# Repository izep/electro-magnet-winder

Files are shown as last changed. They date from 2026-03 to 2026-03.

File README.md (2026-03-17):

# Electro-Magnet Winder

A DIY machine for winding precision electro-magnets and coils, powered by an RP2040-Zero microcontroller.

## Project Structure

| Path | Contents |
|---|---|
| `src/winder.ino` | Firmware (single unified sketch) |
| `wiring/` | Wiring diagrams and pinout references |
| `model/` | 3D-printable STL files for the enclosure |

## Hardware Components

- **Microcontroller**: RP2040-Zero (Waveshare/clone)
- **Motor 1 (winding)**: 28BYJ-48 + ULN2003 driver board
- **Motor 2 (traverse/guide)**: 28BYJ-48 + ULN2003 driver board
- **Display**: SH5461AS 4-digit 7-segment (common cathode)
- **Input**: KY-040 rotary encoder

See `wiring/rp2040-zero-dual-stepper.md` for the full pinout and wiring diagram.

## Getting Started

1. Follow the wiring diagram in `wiring/rp2040-zero-dual-stepper.md`.
2. Install the **Earle Philhower RP2040 Arduino core** in the Arduino IDE.
3. Open `src/winder.ino` and upload to the RP2040-Zero.

## Using the Firmware

On power-up the machine runs a brief motor test (display shows `----`) to confirm both motors are wired correctly. Both motors step forward 4 steps then back 4 steps before the menu appears.

### Menu flow

The **encoder button** advances through each setting. Rotate the encoder to change the current value.

| Display | State | Encoder action |
|---|---|---|
| `0001`  | Layers | Rotate to set number of winding layers (±1, range 1–99) |
| `L 20`  | Spool length | Rotate to set magnet/coil length in mm (±1 mm, range 1–999) |
| `A 28`  | Wire gauge | Rotate to cycle AWG presets: 22, 26, 28, 30, 32, 36, 40 |
| `Hone`  | **Align Guide** | **Rotate to jog guide motor manually; align wire to spool start.** |
| `go` | Ready | Press button to start winding |
| `0000`  | **Winding** | Display counts turns — press button to stop (returns to `Hone`) |

Total turns are computed automatically when you press start:

```
turns_per_layer = floor(spool_length_mm / wire_diameter_mm)
total_turns     = layers × turns_per_layer
```

For example: 3 layers, 20 mm spool, 28 AWG (0.321 mm) → 62 turns/layer → **186 total turns**.

When winding completes (target reached) or is stopped, the machine returns to the turn count setting screen.

### Guide motor calibration

2 revolutions of Motor 2 = 3.5 mm of linear travel. This is fixed in firmware as `GUIDE_STEPS_PER_MM = (2 × 2048) / 3.5 ≈ 1170`. Adjust this constant in `winder.ino` if your lead screw or drive mechanism differs.

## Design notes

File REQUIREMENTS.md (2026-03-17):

# Electro-Magnet Winder - Requirements

## Overview
A DIY machine for winding precision electro-magnets and coils, powered by an RP2040-Zero microcontroller.

## Hardware Specifications
- **Controller**: Waveshare RP2040-Zero
- **Actuators**: 
  - 2x 28BYJ-48 Stepper Motors (64:1 gear ratio)
  - 2x ULN2003 Driver Boards
- **Input**: 
  - KY-040 Rotary Encoder (Navigation and count adjustment)
- **Output**: 
  - 4-Digit 7-Segment Display (SH5461AS, common cathode) for turn count/status.

## Functional Requirements

1. **Menu-driven configuration**: Set target turns, spool/magnet length, and wire gauge before winding.
2. **Automatic Winding**: Press start; machine winds to target turn count and stops automatically.
3. **Dual Motor Sync**:
   - Motor 1: Winding (rotation)
   - Motor 2: Wire guide (linear traverse, ping-pong across spool length)
4. **Display**: Real-time turn count while winding; settings shown in menu.
5. **Wire gauge presets**: 22, 26, 28, 30, 32, 36, 40 AWG — selectable at runtime.
6. **Startup test**: Brief motor movement on power-up to verify coil wiring.
7. **Memory**: Persistence of settings (deferred to future version).

## Technical Stack
- **Firmware**: C++/Arduino (Earle Philhower RP2040 core)
- **CAD**: STL models for 3D printed enclosure
- **Documentation**: Markdown-based wiring and assembly guides

## Roadmap

- [x] Initial wiring and pinout defined
- [x] Basic motor/display test sketch
- [x] Implement traverse/winding sync logic (ping-pong guide)
- [x] Menu system: target turns, spool length, wire gauge, start/stop
- [x] Wire gauge presets (22–40 AWG, selectable at runtime)
- [x] Startup motor test sequence
- [x] Persistence of settings (EEPROM)
- [x] Handle motor release and emergency stop
- [ ] 3D print and assemble enclosure

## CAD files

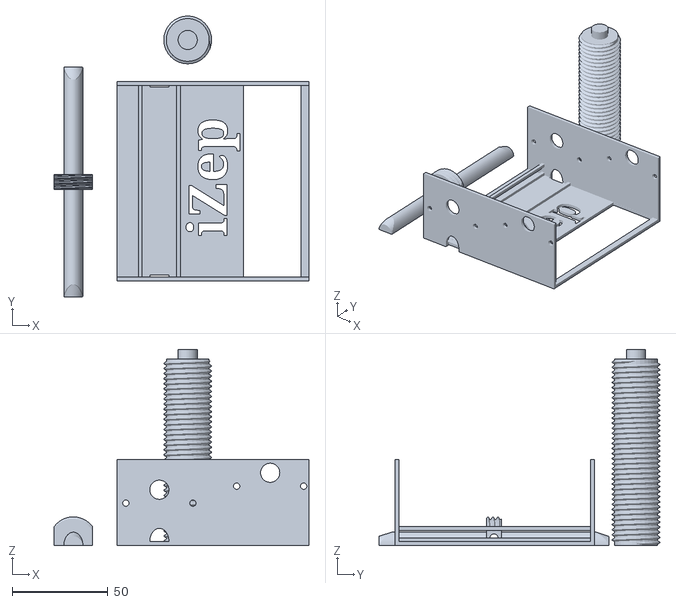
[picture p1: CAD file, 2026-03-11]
model/winder_box.stl
132.9 x 146.7 x 102.4

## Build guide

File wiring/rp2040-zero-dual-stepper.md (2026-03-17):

# RP2040-Zero — Dual Stepper + Display + Rotary Encoder

## Components

| Component | Purpose |
|---|---|
| RP2040-Zero | Main controller |
| 2× 28BYJ-48 + ULN2003 driver boards | Stepper motors |
| SH5461AS 4-digit 7-segment display | Status / count display |
| KY-040 rotary encoder | Adjustment knob + push-button |

The RP2040-Zero exposes **20 GPIO via pin headers**: GP0–GP15 and GP26–GP29.
GP16 drives the onboard WS2812B NeoPixel; GP17–GP25 are castellated-edge only.

To fit within 20 pins, GP0 and GP1 serve dual roles:
- **Menu phase** — reconfigured as `INPUT_PULLDOWN` for encoder CLK/DT
- **Winding phase** — reconfigured as `OUTPUT` for Motor 1 IN1/IN2

GP29 (encoder SW / emergency stop) is always `INPUT_PULLUP` regardless of phase.
The decimal-point segment (DP) is omitted; segments A–G are sufficient for all display needs.

---

## Wiring Diagram

```mermaid
graph LR
    subgraph PWR["⚡ Power"]
        P5V((5 V))
        P3V((3.3 V))
        PGND((GND))
    end

    subgraph RP["RP2040-Zero"]
        R0["GP0  Motor 1 IN1 / Enc CLK ✱"]
        R1["GP1  Motor 1 IN2 / Enc DT  ✱"]
        R2["GP2  Motor 1 IN3"]
        R3["GP3  Motor 1 IN4"]
        R4["GP4  Motor 2 IN1"]
        R5["GP5  Motor 2 IN2"]
        R6["GP6  Motor 2 IN3"]
        R7["GP7  Motor 2 IN4"]
        R8["GP8  Seg A"]
        R9["GP9  Seg B"]
        R10["GP10 Seg C"]
        R11["GP11 Seg D"]
        R12["GP12 Seg E"]
        R13["GP13 Seg F"]
        R14["GP14 Seg G"]
        R15["GP15 Digit 0"]
        R26["GP26 Digit 1"]
        R27["GP27 Digit 2"]
        R28["GP28 Digit 3"]
        R29["GP29 Enc SW (always)"]
        RGND["GND"]
    end

    subgraph U1["ULN2003 Driver #1"]
        U1IN["IN1-IN4"]
        U1VCC["VCC / +"]
        U1GND["GND / -"]
        U1OUT["Motor JST"]
    end

    subgraph U2["ULN2003 Driver #2"]
        U2IN["IN1-IN4"]
        U2VCC["VCC / +"]
        U2GND["GND / -"]
        U2OUT["Motor JST"]
    end

    subgraph DISP["SH5461AS (common cathode)"]
        DSA["Seg A–G"]
        DDG["Digit 0–3 cathodes"]
    end

    subgraph KY["KY-040 Rotary Encoder"]
        KCLK["CLK (A)"]
        KDT["DT (B)"]
        KSW["SW"]
        KVCC["VCC"]
        KGND["GND"]
    end

    M1["Motor 1\n28BYJ-48"]
    M2["Motor 2\n28BYJ-48"]

    %% Motor 1 wiring
    R0 & R1 & R2 & R3 -- "IN1-IN4" --> U1IN
    %% Motor 2 wiring
    R4 & R5 & R6 & R7 -- "IN1-IN4" --> U2IN

    %% Display segments (via 150Ω resistors)
    R8 & R9 & R10 & R11 & R12 & R13 & R14 -- "150Ω" --> DSA
    %% Display digit selects
    R15 & R26 & R27 & R28 --> DDG

    %% Encoder (CLK/DT shared with Motor 1 IN1/IN2 — menu phase only)
    R0 -.->|"menu only ✱"| KCLK
    R1 -.->|"menu only ✱"| KDT
    R29 --> KSW

    %% Motors
    U1OUT --> M1
    U2OUT --> M2

    %% Power 5V
    P5V --> U1VCC
    P5V --> U2VCC

    %% Power 3.3V
    P3V --> KVCC

    %% GND
    PGND --> U1GND
    PGND --> U2GND
    PGND --> KGND
    PGND --> RGND
```

---

## RP2040-Zero Pin Reference

> ✱ GP0 and GP1 are shared. The firmware reconfigures them at each phase boundary.

| GPIO | Role | Connected to | Phase |
|---|---|---|---|
| GP0 | Motor 1 IN1 | ULN2003 #1 IN1 | Winding |
| GP0 ✱ | Encoder CLK | KY-040 CLK | Menu |
| GP1 | Motor 1 IN2 | ULN2003 #1 IN2 | Winding |
| GP1 ✱ | Encoder DT | KY-040 DT | Menu |
| GP2 | Motor 1 IN3 | ULN2003 #1 IN3 | Both |
| GP3 | Motor 1 IN4 | ULN2003 #1 IN4 | Both |
| GP4 | Motor 2 IN1 | ULN2003 #2 IN1 | Both |
| GP5 | Motor 2 IN2 | ULN2003 #2 IN2 | Both |
| GP6 | Motor 2 IN3 | ULN2003 #2 IN3 | Both |
| GP7 | Motor 2 IN4 | ULN2003 #2 IN4 | Both |
| GP8 | Segment A | SH5461AS pin 11 (via 150 Ω) | Both |
| GP9 | Digit 1 cathode | SH5461AS pin 12 (leftmost) | Both |
| GP10 | Segment C | SH5461AS pin 4 (via 150 Ω) | Both |
| GP11 | Segment D | SH5461AS pin 2 (via 150 Ω) | Both |
| GP12 | Segment E | SH5461AS pin 1 (via 150 Ω) | Both |
| GP13 | Digit 2 cathode | SH5461AS pin 9 | Both |
| GP14 | Segment G | SH5461AS pin 5 (via 150 Ω) | Both |
| GP15 | Segment F | SH5461AS pin 10 (via 150 Ω) | Both |
| GP26 | Digit 3 cathode | SH5461AS pin 8 | Both |
| GP27 | Segment B | SH5461AS pin 7 (via 150 Ω) | Both |
| GP28 | Digit 4 cathode | SH5461AS pin 6 (rightmost) | Both |
| GP29 | Encoder SW | KY-040 SW (emergency stop) | Both |

DP segment is not connected. All 20 header-accessible GPIO are used.

---

## RP2040-Zero → ULN2003 Stepper Detail

The RP2040-Zero's 3.3 V GPIO outputs exceed the ULN2003's ~2.5 V input
threshold — no level shifter required. Motor coil power stays on the 5 V rail
via the ULN2003 boards.

### Motor 1 (GP0–GP3)

| RP2040-Zero | ULN2003 #1 |
|---|---|
| GP0 | IN1 |
| GP1 | IN2 |
| GP2 | IN3 |
| GP3 | IN4 |

### Motor 2 (GP4–GP7)

| RP2040-Zero | ULN2003 #2 |
|---|---|
| GP4 | IN1 |
| GP5 | IN2 |
| GP6 | IN3 |
| GP7 | IN4 |

---

## RP2040-Zero → SH5461AS Display Detail

The SH5461AS is a **common-cathode** display. To light a segment: pull the
digit pin LOW and the segment pin HIGH. Cycle through digits rapidly to
multiplex.

Place a **150 Ω resistor** in series with each segment line (GP8–GP14). At
3.3 V with a ~2 V LED forward voltage and 25% multiplex duty cycle this gives
roughly 8–9 mA per segment — adequate brightness without overloading the GPIO.

### Physical Pinout

The SH5461AS has **12 pins** — 6 on the bottom edge and 6 on the top edge.

**Finding pin 1:** Hold the display face-toward-you with the decimal points
along the bottom edge. The small circular indent (or dot) moulded into the
plastic body marks the **pin 1 end**. Pin 1 is the bottom-left pin.

```
        FRONT VIEW  (decimal points along bottom, pin-1 dot at bottom-left)

        pin 12  11  10   9   8   7
              │   │   │   │   │   │
         ┌────┴───┴───┴───┴───┴───┴────┐
         │                             │
         │   ┌──┐  ┌──┐  ┌──┐  ┌──┐   │
         │   │  │  │  │  │  │  │  │   │
         │   └──┘  └──┘  └──┘  └──┘   │
         │    D1    D2    D3    D4     │
         │    .     .     .     .     │  ← decimal points (not wired)
         └────┬───┬───┬───┬───┬───┬───┘
              │   │   │   │   │   │
         ● pin 1   2   3   4   5   6
         (dot)
```

Pin functions:

| Pin | Function | Pin | Function |
|-----|---|-----|---|
|  1  | Segment E |  7  | Digit 3 cathode (D3) |
|  2  | Segment D |  8  | Digit 2 cathode (D2) |
|  3  | Segment DP |  9  | Segment F |
|  4  | Segment C | 10  | Digit 1 cathode (D1, leftmost) |
|  5  | Segment G | 11  | Segment A |
|  6  | Digit 4 cathode (D4, rightmost) | 12 | Segment B |

### Wiring to RP2040-Zero

| RP2040-Zero | Resistor | SH5461AS pin | Signal |
|---|---|---|---|
| GP8  | 150 Ω | Pin 11 | Segment A |
| GP27 | 150 Ω | Pin 7  | Segment B |
| GP10 | 150 Ω | Pin 4  | Segment C |
| GP11 | 150 Ω | Pin 2  | Segment D |
| GP12 | 150 Ω | Pin 1  | Segment E |
| GP15 | 150 Ω | Pin 10 | Segment F |
| GP14 | 150 Ω | Pin 5  | Segment G |
| GP9  | — | Pin 12 | Digit 1 cathode (leftmost) |
| GP13 | — | Pin 9  | Digit 2 cathode |
| GP26 | — | Pin 8  | Digit 3 cathode |
| GP28 | — | Pin 6  | Digit 4 cathode (rightmost) |

Pin 3 (Segment DP) is left unconnected.

---

## GP0 / GP1 Pin Sharing

GP0 and GP1 connect to **both** ULN2003 #1 (IN1/IN2) and the KY-040 encoder (CLK/DT).
The firmware switches their role at phase boundaries:

| Phase | pinMode | Effect |
|---|---|---|
| Menu | `INPUT_PULLDOWN` | KY-040's 10 kΩ pull-ups drive the lines; ULN2003 inputs held LOW (motors off) |
| Winding | `OUTPUT` | Normal motor step outputs; encoder CLK/DT signals are ignored |

`enterMenuMode()` detaches the CLK interrupt, reconfigures to `INPUT_PULLDOWN`, then re-attaches.  
`enterWindingMode()` detaches the interrupt and reconfigures to `OUTPUT LOW`.

GP29 (encoder SW) is wired **only** to the KY-040 SW pin and stays `INPUT_PULLUP` always,
so the emergency-stop button works during both menu navigation and active winding.

---

## Power Summary

| Rail | Feeds |
|---|---|
| 5 V (USB or external ≥ 1 A) | ULN2003 boards |
| 3.3 V (RP2040-Zero onboard reg) | KY-040, SH5461AS segments |
| GND | Shared — connect all grounds together |

Both motors can draw ~240 mA each under load (480 mA combined). Use a
dedicated external 5 V supply for the ULN2003 boards when both motors run.

---

## Stepper Half-Step Sequence

| Step | IN4 | IN3 | IN2 | IN1 | Nibble |
|---|-----|-----|-----|-----|---|
| 1 | 0 | 0 | 0 | 1 | 0x1 |
| 2 | 0 | 0 | 1 | 1 | 0x3 |
| 3 | 0 | 0 | 1 | 0 | 0x2 |
| 4 | 0 | 1 | 1 | 0 | 0x6 |
| 5 | 0 | 1 | 0 | 0 | 0x4 |
| 6 | 1 | 1 | 0 | 0 | 0xC |
| 7 | 1 | 0 | 0 | 0 | 0x8 |
| 8 | 1 | 0 | 0 | 1 | 0x9 |

Reverse the table for reverse direction.
**2048 steps = 1 full revolution** (64:1 gearbox × 32 full steps, half-step mode).

---

## Firmware

The full Arduino sketch lives in [`../src/winder.ino`](../src/winder.ino).
Use the **Earle Philhower RP2040 Arduino core** (`arduino-pico`). No extra
libraries needed — all I/O is direct GPIO.

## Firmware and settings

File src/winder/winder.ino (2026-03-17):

#include "hardware/gpio.h"
/**
 * Electro-Magnet Winder Firmware
 * Target: Waveshare RP2040-Zero
 * Core:   Earle Philhower RP2040 Arduino core
 */

#include <Arduino.h>
#include <EEPROM.h>
#include "EEPROM_Settings.h"

SettingsManager settingsManager;

// ── Pin assignments ──────────────────────────────────────────────────────────

const int M1[4]  = {0, 1, 2, 3};             // Winding motor  (ULN2003 #1)
const int M2[4]  = {4, 5, 6, 7};             // Traverse motor (ULN2003 #2)
const int SEG[7] = {8, 27, 10, 11, 12, 15, 14};  // Segments A, B, C, D, E, F, G
const int DIG[4] = {9, 13, 26, 28};             // Digit cathodes 1, 2, 3, 4

#define ENC_CLK  0
#define ENC_DT   1
#define ENC_SW  29

// ── Motor constants ──────────────────────────────────────────────────────────

const int   STEPS_PER_REV      = 4096;       // 28BYJ-48 half-step (64:1 gear)
const float GUIDE_STEPS_PER_MM = 1575.385f;  // From calibration (61440 steps / 39mm)
const int   STEP_DELAY_MS      = 2;          // ms between winding motor steps

// ── AWG wire diameter presets ────────────────────────────────────────────────

struct WireGauge { uint8_t awg; float diameter_mm; };

const WireGauge GAUGES[] = {
  {22, 0.644f}, {26, 0.405f}, {28, 0.321f}, {30, 0.255f},
  {32, 0.202f}, {36, 0.127f}, {40, 0.079f},
};
const int NUM_GAUGES = (int)(sizeof(GAUGES) / sizeof(GAUGES[0]));

// ── Half-step sequence ───────────────────────────────────────────────────────

const uint8_t HALF_STEP[8] = {0x1, 0x3, 0x2, 0x6, 0x4, 0xC, 0x8, 0x9};

// ── 7-segment patterns ───────────────────────────────────────────────────────

const uint8_t DIGIT_PAT[10] = {
  0b00111111, 0b00000110, 0b01011011, 0b01001111, 0b01100110,
  0b01101101, 0b01111101, 0b00000111, 0b01111111, 0b01101111,
};

const uint8_t SEG_BLANK = 0x00;
const uint8_t SEG_DASH  = 0x40;
const uint8_t SEG_L     = 0x38;
const uint8_t SEG_A_UP  = 0x77;
const uint8_t SEG_G_LO  = 0x6F;
const uint8_t SEG_O_LO  = 0x5C;
const uint8_t SEG_D_LO  = 0x5E;
const uint8_t SEG_N_LO  = 0x54;
const uint8_t SEG_E_LO  = 0x79;
const uint8_t SEG_H     = 0x76;
const uint8_t SEG_C_UP  = 0x39;

// ── State & Defaults ─────────────────────────────────────────────────────────

enum State { MENU_LAYERS, MENU_LENGTH, MENU_GAUGE, MENU_DIR, MENU_HOME, MENU_START, WINDING };
State state = MENU_LAYERS;

int targetLayers  = 10;   // Default: 10 layers
int spoolLengthMM = 50;   // Default: 50 mm
int gaugeIndex    = 0;    // Default: 22 AWG
int guideDir      = -1;   // Default: CC (-1)

uint8_t displayBuf[4] = {SEG_BLANK, SEG_BLANK, SEG_BLANK, SEG_BLANK};

// ── Winding state ────────────────────────────────────────────────────────────

int           computedTurns = 0;
long          totalStepsM1 = 0;
long          totalStepsM2 = 0;
int           currentTurns = 0;
int           stepIdx1     = 0;
int           stepIdx2     = 0;
unsigned long lastStepTime = 0;

volatile int encoderDelta = 0;

void onEncoderCLK() {
  static uint32_t lastISR = 0;
  uint32_t now = millis();
  if (now - lastISR < 1) return;
  lastISR = now;
  encoderDelta += (digitalRead(ENC_DT) == HIGH) ? -1 : 1;
}

// ── Motor helpers ────────────────────────────────────────────────────────────

void writeMotor(const int pins[4], uint8_t nibble) {
  for (int i = 0; i < 4; i++) digitalWrite(pins[i], (nibble >> i) & 1);
}

void stepMotor1(int dir) {
  stepIdx1 = (stepIdx1 + dir + 8) % 8;
  writeMotor(M1, HALF_STEP[stepIdx1]);
  totalStepsM1 += dir;
}

void stepMotor2(int dir) {
  stepIdx2 = (stepIdx2 + dir + 8) % 8;
  writeMotor(M2, HALF_STEP[stepIdx2]);
  totalStepsM2 += dir;
}

void releaseMotors() { writeMotor(M1, 0); writeMotor(M2, 0); }

void enterMenuMode() {
  writeMotor(M1, 0);
  detachInterrupt(digitalPinToInterrupt(ENC_CLK));
  pinMode(ENC_CLK, INPUT_PULLDOWN);
  pinMode(ENC_DT,  INPUT_PULLDOWN);
  encoderDelta = 0;
  attachInterrupt(digitalPinToInterrupt(ENC_CLK), onEncoderCLK, FALLING);
}

void enterWindingMode() {
  detachInterrupt(digitalPinToInterrupt(ENC_CLK));
  pinMode(ENC_CLK, OUTPUT); digitalWrite(ENC_CLK, LOW);
  pinMode(ENC_DT,  OUTPUT); digitalWrite(ENC_DT,  LOW);
}

// ── Display helpers ──────────────────────────────────────────────────────────

void refreshDisplay() {
  static uint8_t digit = 0;
  for (int i = 0; i < 4; i++) digitalWrite(DIG[i], HIGH);
  uint8_t pat = displayBuf[digit];
  for (int i = 0; i < 7; i++) digitalWrite(SEG[i], (pat >> i) & 1);
  digitalWrite(DIG[digit], LOW);
  digit = (digit + 1) % 4;
}

void showNumber(int n) {
  n = constrain(n, 0, 9999);
  displayBuf[0] = (n >= 1000) ? DIGIT_PAT[n / 1000] : SEG_BLANK;
  displayBuf[1] = (n >= 100)  ? DIGIT_PAT[(n / 100) % 10] : SEG_BLANK;
  displayBuf[2] = (n >= 10)   ? DIGIT_PAT[(n / 10)  % 10] : SEG_BLANK;
  displayBuf[3] = DIGIT_PAT[n % 10];
}

void motorStartupTest() {
  for (int i = 0; i < 4; i++) displayBuf[i] = SEG_DASH;
  for (int i = 0; i < 400; i++) { stepMotor1( 1); refreshDisplay(); delay(2); }
  for (int i = 0; i < 400; i++) { stepMotor1(-1); refreshDisplay(); delay(2); }
  for (int i = 0; i < 400; i++) { stepMotor2( 1); refreshDisplay(); delay(2); }
  for (int i = 0; i < 400; i++) { stepMotor2(-1); refreshDisplay(); delay(2); }
  releaseMotors();
}

void updateDisplay() {
  switch (state) {
    case MENU_LAYERS: showNumber(targetLayers); break;
    case MENU_LENGTH: {
      int n = constrain(spoolLengthMM, 0, 999);
      displayBuf[0] = SEG_L;
      displayBuf[1] = (n >= 100) ? DIGIT_PAT[n / 100] : SEG_BLANK;
      displayBuf[2] = (n >= 10)  ? DIGIT_PAT[(n / 10) % 10] : SEG_BLANK;
      displayBuf[3] = DIGIT_PAT[n % 10];
      break;
    }
    case MENU_GAUGE:
      displayBuf[0] = SEG_A_UP; displayBuf[1] = SEG_BLANK;
      displayBuf[2] = DIGIT_PAT[GAUGES[gaugeIndex].awg / 10];
      displayBuf[3] = DIGIT_PAT[GAUGES[gaugeIndex].awg % 10];
      break;
    case MENU_DIR:
      displayBuf[0] = SEG_D_LO; displayBuf[1] = SEG_BLANK;
      displayBuf[2] = SEG_C_UP; 
      displayBuf[3] = (guideDir == 1) ? SEG_BLANK : SEG_C_UP; // "d  C" or "d CC"
      break;
    case MENU_HOME:
      displayBuf[0] = SEG_H; displayBuf[1] = SEG_O_LO;
      displayBuf[2] = SEG_N_LO; displayBuf[3] = SEG_E_LO;
      break;
    case MENU_START:
      displayBuf[0] = SEG_G_LO; displayBuf[1] = SEG_O_LO;
      displayBuf[2] = SEG_BLANK; displayBuf[3] = SEG_BLANK;
      break;
    case WINDING: showNumber(currentTurns); break;
  }
}

void handleEncoder() {
  noInterrupts(); int delta = encoderDelta; encoderDelta = 0; interrupts();
  if (delta == 0) return;
  bool changed = false;
  switch (state) {
    case MENU_LAYERS: targetLayers = constrain(targetLayers + delta, 1, 99); settingsManager.current.targetLayers = targetLayers; changed = true; break;
    case MENU_LENGTH: spoolLengthMM = constrain(spoolLengthMM + delta, 1, 999); settingsManager.current.spoolLengthMM = spoolLengthMM; changed = true; break;
    case MENU_GAUGE:  gaugeIndex = (gaugeIndex + delta + NUM_GAUGES) % NUM_GAUGES; settingsManager.current.gaugeIndex = gaugeIndex; changed = true; break;
    case MENU_DIR:    if (delta != 0) { guideDir *= -1; settingsManager.current.guideDir = guideDir; changed = true; } break;
    case MENU_HOME: {
      // 1 Encoder rotation (~20 clicks) = 1 Motor rotation (4096 steps)
      int steps = delta * 205; 
      int dir = (steps > 0) ? 1 : -1;
      for (int i = 0; i < abs(steps); i++) { stepMotor2(dir); delay(2); if (i % 4 == 0) refreshDisplay(); }
      releaseMotors(); break;
    }
    default: break;
  }
  if (changed) settingsManager.save();
}

void handleButton() {
  if (digitalRead(ENC_SW) != LOW) return;
  delay(20); while (digitalRead(ENC_SW) == LOW); delay(20);
  switch (state) {
    case MENU_LAYERS: state = MENU_LENGTH; break;
    case MENU_LENGTH: state = MENU_GAUGE;  break;
    case MENU_GAUGE:  state = MENU_DIR;    break;
    case MENU_DIR:    state = MENU_HOME;   break;
    case MENU_HOME:   state = MENU_START;  break;
    case MENU_START: {
      float wireDiam = GAUGES[gaugeIndex].diameter_mm;
      int turnsPerLayer = max(1, (int)((float)spoolLengthMM / wireDiam));
      computedTurns = targetLayers * turnsPerLayer;
      enterWindingMode();
      state = WINDING; currentTurns = 0; totalStepsM1 = 0; totalStepsM2 = 0;
      lastStepTime = millis(); break;
    }
    case WINDING: releaseMotors(); enterMenuMode(); state = MENU_HOME; break;
  }
}

void handleWinding() {
  if (currentTurns >= computedTurns) {
    releaseMotors();
    displayBuf[0] = SEG_D_LO; displayBuf[1] = SEG_O_LO; displayBuf[2] = SEG_N_LO; displayBuf[3] = SEG_E_LO;
    unsigned long t = millis(); while (millis() - t < 2000) refreshDisplay();
    enterMenuMode(); state = MENU_LAYERS; return;
  }
  if (millis() - lastStepTime < (unsigned long)STEP_DELAY_MS) return;
  lastStepTime = millis();

  stepMotor1(1); // Spindle Clockwise

  float wireDiam = GAUGES[gaugeIndex].diameter_mm;
  float passLength = (float)spoolLengthMM;
  float totalRevs = (float)totalStepsM1 / STEPS_PER_REV;
  float targetMM = totalRevs * wireDiam;
  
  int passNum = (int)(targetMM / passLength);
  float posInPass = fmod(targetMM, passLength);
  
  // Logic: guideMM always starts at 0 relative to Hone. 
  // Physical direction is controlled by multiplying by guideDir.
  float guideMM = (passNum % 2 == 0) ? posInPass : passLength - posInPass;
  
  long targetStepsM2 = (long)(guideMM * GUIDE_STEPS_PER_MM * (float)guideDir);

  if (totalStepsM2 < targetStepsM2) stepMotor2(1); 
  else if (totalStepsM2 > targetStepsM2) stepMotor2(-1);

  currentTurns = (int)(totalStepsM1 / STEPS_PER_REV);
}

void setup() {
  settingsManager.begin();
  targetLayers = settingsManager.current.targetLayers;
  spoolLengthMM = settingsManager.current.spoolLengthMM;
  gaugeIndex = settingsManager.current.gaugeIndex;
  guideDir = settingsManager.current.guideDir;
  for (int i = 0; i < 4; i++) { pinMode(M1[i], OUTPUT); digitalWrite(M1[i], LOW); }
  for (int i = 0; i < 4; i++) { pinMode(M2[i], OUTPUT); digitalWrite(M2[i], LOW); }
  for (int i = 0; i < 7; i++) { pinMode(SEG[i], OUTPUT); digitalWrite(SEG[i], LOW); }
  for (int i = 0; i < 4; i++) { pinMode(DIG[i], OUTPUT); digitalWrite(DIG[i], HIGH); gpio_set_drive_strength((uint)DIG[i], GPIO_DRIVE_STRENGTH_12MA); }
  pinMode(ENC_SW, INPUT_PULLUP);
  motorStartupTest(); enterMenuMode(); updateDisplay();
}

void loop() { refreshDisplay(); handleButton(); if (state == WINDING) handleWinding(); else handleEncoder(); updateDisplay(); }

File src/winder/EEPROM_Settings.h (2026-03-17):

#ifndef EEPROM_SETTINGS_H
#define EEPROM_SETTINGS_H

#include <Arduino.h>
#include <EEPROM.h>

struct Settings {
  uint32_t magic; // 0x534B4950 (SKIP)
  int targetLayers;
  int spoolLengthMM;
  int gaugeIndex;
  int guideDir;
};

const uint32_t MAGIC_VAL = 0x534B4950;

class SettingsManager {
public:
  Settings current;

  void begin() {
    EEPROM.begin(512);
    load();
  }

  void load() {
    EEPROM.get(0, current);
    if (current.magic != MAGIC_VAL) {
      // Default settings
      current.magic = MAGIC_VAL;
      current.targetLayers = 10;
      current.spoolLengthMM = 50;
      current.gaugeIndex = 0;
      current.guideDir = -1;
      save();
    }
  }

  void save() {
    EEPROM.put(0, current);
    EEPROM.commit();
  }
};

extern SettingsManager settingsManager;

#endif

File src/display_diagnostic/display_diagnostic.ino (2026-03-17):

/*
 * Display Diagnostic Program V2
 * Corrected mapping for SH5461AS Standard Pinout 
 * (Matches README physical wiring but fixes logical assignments)
 */

// Logical mapping based on standard datasheet functions of the pins you connected:
const int segmentPins[] = {8, 27, 10, 11, 12, 15, 14}; // A, B, C, D, E, F, G
const char segmentNames[] = {'A', 'B', 'C', 'D', 'E', 'F', 'G'};

// Digits based on standard datasheet functions of the pins you connected:
const int digitPins[] = {9, 13, 26, 28}; // Digit 1 (L), 2, 3, 4 (R)

void setup() {
  Serial.begin(115200);
  
  // Initialize all pins as OUTPUT
  for (int i = 0; i < 7; i++) {
    pinMode(segmentPins[i], OUTPUT);
    digitalWrite(segmentPins[i], LOW);
  }
  for (int i = 0; i < 4; i++) {
    pinMode(digitPins[i], OUTPUT);
    digitalWrite(digitPins[i], HIGH); // Common Cathode: HIGH = OFF
  }
  
  Serial.println("Display Diagnostic V2 Started");
  Serial.println("Using corrected logical mapping for standard SH5461AS.");
}

void loop() {
  // Test 1: All segments of all digits (Verify Polarity CC vs CA)
  Serial.println("Testing Polarity: All segments ON (Common Cathode mode)");
  for (int d = 0; d < 4; d++) digitalWrite(digitPins[d], LOW);
  for (int s = 0; s < 7; s++) digitalWrite(segmentPins[s], HIGH);
  delay(2000);
  for (int s = 0; s < 7; s++) digitalWrite(segmentPins[s], LOW);
  for (int d = 0; d < 4; d++) digitalWrite(digitPins[d], HIGH);
  delay(500);

  // Test 2: Sequential Scan
  for (int d = 0; d < 4; d++) {
    Serial.print("Testing Digit "); Serial.println(d + 1);
    digitalWrite(digitPins[d], LOW); 
    
    for (int s = 0; s < 7; s++) {
      Serial.print("  Segment "); Serial.println(segmentNames[s]);
      digitalWrite(segmentPins[s], HIGH);
      delay(400);
      digitalWrite(segmentPins[s], LOW);
      delay(100);
    }
    digitalWrite(digitPins[d], HIGH);
    delay(300);
  }
}

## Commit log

2026-03-11 Initial commit: RP2040-Zero wiring doc, STL model, gitignore
    [winder_box.stl]
2026-03-11 feat: implement dual-stepper ping-pong guide logic
2026-03-11 Initial commit: Electro-Magnet Winder foundation
2026-03-11 feat: unified firmware with menu system, AWG presets, and bug fixes
    - Replace src/main.cpp + src/winder_v1.ino with src/winder.ino
    - Menu flow: TURNS → LENGTH → GAUGE → START → WINDING
    - TURNS: encoder sets target turn count (±10, 10–9990)
    - LENGTH: encoder sets magnet/spool length in mm (±1, 1–999)
    - GAUGE: encoder cycles AWG presets (22, 26, 28, 30, 32, 36, 40)
    - START: display shows 'go', button begins winding
    - WINDING: live turn count, button stops early
    - Guide motor calibrated: 2 rev = 3.5 mm → ~1170 steps/mm
    - Ping-pong traverse synced to wire diameter and spool length
    - Startup motor test on boot (display shows '----')
    - Bug fixes from code review:
    - S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
    [winder.ino]
2026-03-11 feat: replace target turns with layers-based winding configuration
    Total turns now computed automatically:
    turns_per_layer = floor(spool_length_mm / wire_diameter_mm)
    total_turns = layers × turns_per_layer
    Changes:
    - MENU_TURNS → MENU_LAYERS (encoder ±1, range 1–99)
    - targetTurns removed; computedTurns calculated at winding start
    - computedTurns drives winding completion check
    - Stop and auto-complete both return to MENU_LAYERS
    - README updated with formula and example
    [winder.ino]
2026-03-12 Remap pins to fit RP2040-Zero's 20 header GPIOs
    - GP0/GP1: shared between Motor 1 IN1/IN2 (winding) and ENC_CLK/DT (menu)
    - Menu phase: INPUT_PULLDOWN — encoder readable, motor coils de-energised
    - Winding phase: OUTPUT — normal motor step outputs
    - GP29: dedicated ENC_SW (emergency stop, always INPUT_PULLUP)
    - DIG[4] moved to GP15, GP26, GP27, GP28 (all header-accessible)
    - SEG[7] = GP8–GP14 (DP dropped; 7 segments sufficient)
    - Add enterMenuMode() / enterWindingMode() phase transition helpers
    - Winding display now shows actual turn count (up to 9999) instead of %
    - Fix wiring doc: correct false '29 usable GPIO' claim, update Mermaid
    diagram, pin table, add GP0/GP1 pin-sharing s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
    [winder.ino]
2026-03-12 Add SH5461AS physical pinout diagram and numbered wiring table
    Explains how to find pin 1 (moulded dot), shows ASCII front-view
    diagram with pin numbers, and maps each physical pin number to its
    segment/digit function and the corresponding RP2040-Zero GPIO.
2026-03-13 feat: Add 24 AWG preset to winder firmware
2026-03-13 Fix: Synchronized traverse logic and emergency stop support
    [winder.ino]
2026-03-13 chore: Skippy slightly sped up the motor test, you humans are so slow
    [winder.ino]
2026-03-14 docs: Update requirements to reflect current implementation status
2026-03-14 Calibrated winding math and improved traverse sync logic
2026-03-14 feat: Add motor speed configuration to menu and persistence
2026-03-15 fix: Calibrate GUIDE_STEPS_PER_MM constant based on README specifications
    [winder.ino]
2026-03-16 fix: Reverse motor phase sequence for correct clockwise rotation
    [winder.ino]
2026-03-17 Correct SH5461AS pinout, add 'Hone' alignment, and calibrate guide motor
    - Fix: Remapped display pins GP8-GP28 to match standard SH5461AS physical pinout
    - Feat: Added 'Hone' (Align Guide) menu state with encoder-based jogging
    - Feat: Added 'dir' menu to toggle guide starting direction (C/CC)
    - Fix: Updated STEPS_PER_REV to 4096 and calibrated GUIDE_STEPS_PER_MM to 1575.385
    - Docs: Updated README and wiring diagrams with verified pin mappings and menu flow
    - Tools: Added display diagnostic and guide calibration scripts to src/
    [calibrate_guide.ino, display_diagnostic.ino, winder.ino]
2026-03-23 chore: add top-level winder.ino wrapper for Arduino IDE compatibility
